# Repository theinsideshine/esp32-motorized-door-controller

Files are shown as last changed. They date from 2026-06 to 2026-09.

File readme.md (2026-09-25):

# ESP32 Motorized Door Controller

<p align="center">
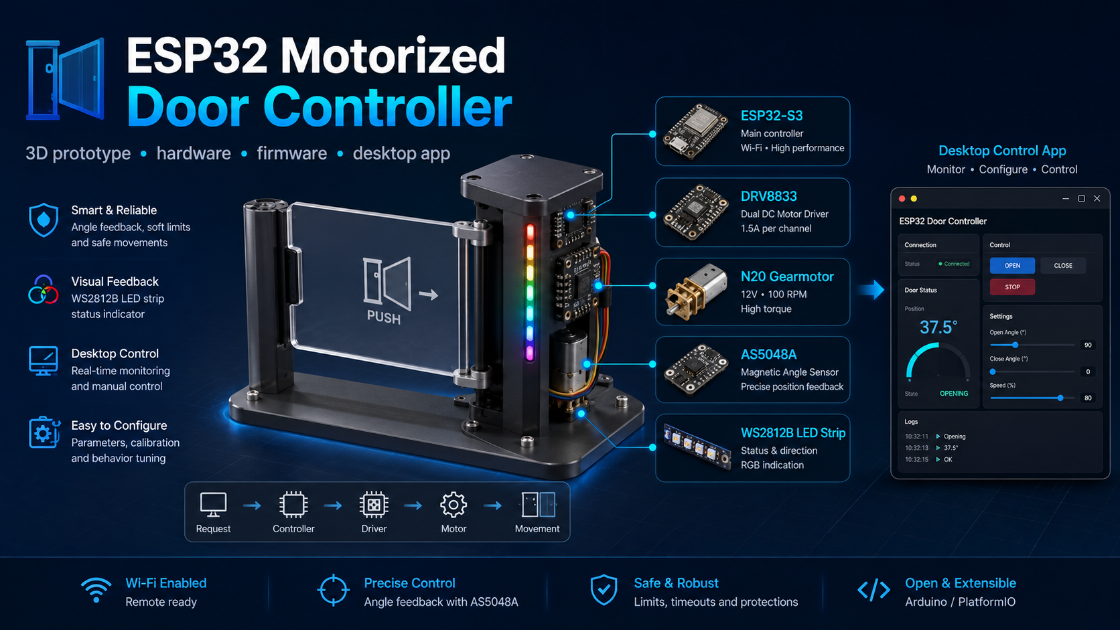
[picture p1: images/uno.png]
ESP32 Motorized Door Controller
  
</p>

> Prototipo funcional a escala de una puerta motorizada de paso, desarrollado como proyecto integrador de I+D para recorrer de forma práctica diseño mecánico, electrónica, firmware embebido, identificación de planta, control y aplicación de escritorio.

---

## 1. Visión del proyecto

Este repositorio documenta la evolución completa de un sistema de control para una **puerta motorizada de paso** basada en ESP32-S3.

El objetivo no fue simplemente lograr que un motor girara hasta una posición. El proyecto se utilizó como un caso de estudio de Ingeniería Electrónica para mostrar cómo una solución real evoluciona mediante:

- diseño CAD e impresión 3D;
- selección e integración de hardware;
- validación experimental;
- firmware monolítico inicial;
- arquitectura modular;
- configuración persistente;
- máquinas de estado;
- instrumentación y Serial Plotter;
- identificación de planta;
- simulación;
- control realimentado;
- diagnóstico de fallas;
- señalización LED;
- aplicación de escritorio.

La idea central es **aprender haciendo**: adquirir conocimientos, aplicarlos sobre un objetivo concreto y convertir las pruebas, errores y decisiones de diseño en competencias profesionales.

---

## 2. Alcance del prototipo

En un desarrollo industrial real se construiría un prototipo funcional representativo del producto final.

A los efectos de este proyecto se implementó un **prototipo funcional a escala**, fabricado principalmente mediante impresión 3D y componentes electrónicos comerciales de bajo costo.

El prototipo permite estudiar el comportamiento del sistema y validar decisiones de arquitectura y control, pero no pretende reproducir todavía:

- dimensiones reales;
- materiales de producción;
- resistencia estructural;
- mecanismos de seguridad certificados;
- embragues o trabas mecánicas de una puerta comercial;
- cargas, inercias y tolerancias de una unidad de tamaño real.

---

## 3. Arquitectura actual

<p align="center">
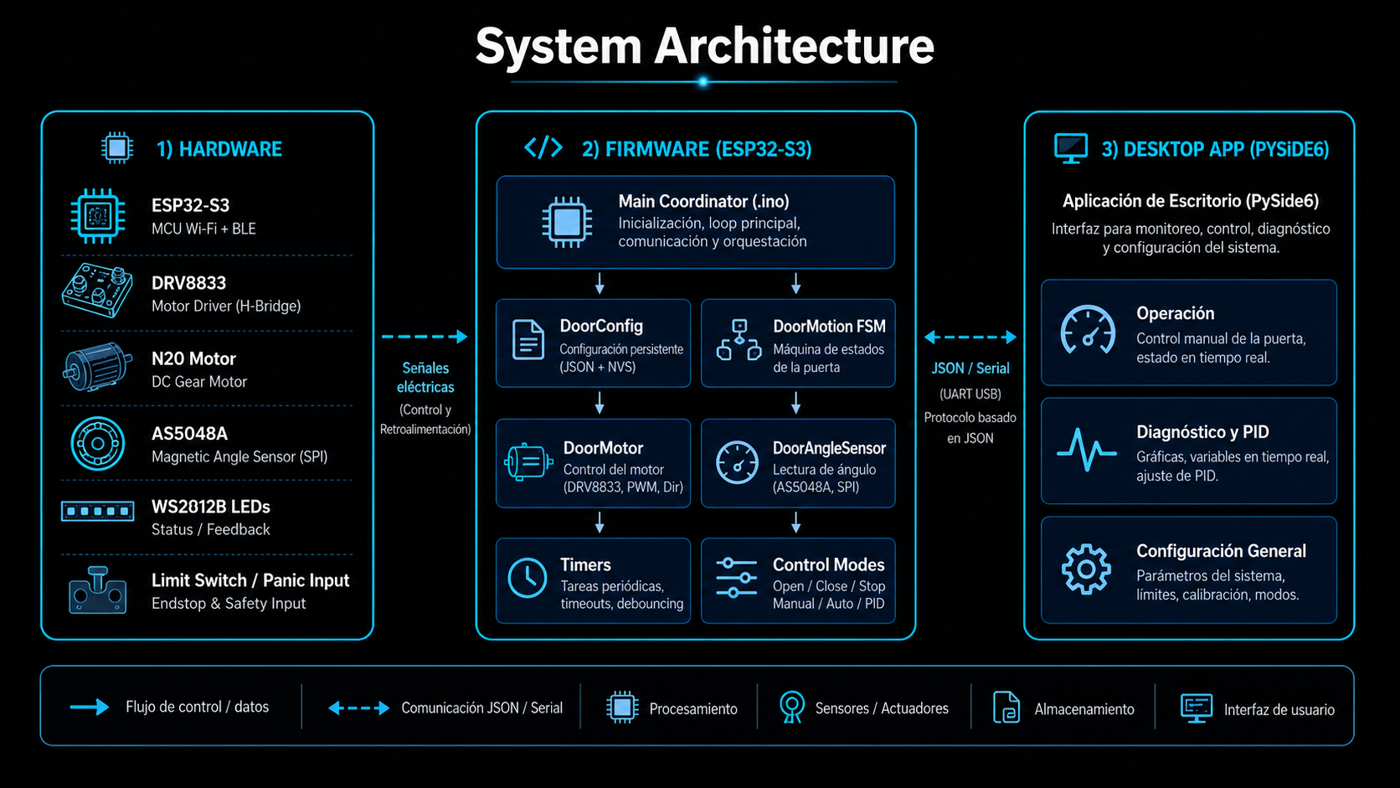
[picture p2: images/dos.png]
Arquitectura general del sistema
  
</p>

La arquitectura separa claramente las responsabilidades principales:

### Hardware

- **ESP32-S3 Dev Module**
- **DRV8833** como puente H
- **Motorreductor N20 de 6 V**
- **AS5048A** como sensor absoluto de posición angular por SPI
- **WS2812B** para señalización visual
- entrada de final de carrera / seguridad
- estructura y mecanismos impresos en 3D

### Firmware

El firmware evolucionó desde un único `.ino` experimental hacia una arquitectura modular.

Responsabilidades principales:

- `motorized_door.ino`  
  Coordinación general del dispositivo.

- `door_config.*`  
  Comunicación JSON, parámetros de configuración, persistencia NVS y requests del host.

- `door_motion.*`  
  Máquina de estados de posicionamiento y estrategias de movimiento.

- `door_motor.*`  
  Abstracción del DRV8833, dirección y PWM.

- `door_angle_sensor.*`  
  Lectura del AS5048A.

- logging / instrumentación  
  Salida humana, JSON de estado y datos para Plotter.

Una decisión importante fue mantener separadas:

1. la lógica del producto;
2. la máquina de posicionamiento;
3. el acceso al hardware;
4. la comunicación;
5. la configuración persistente.

Esto permitió modificar estrategias de control sin reescribir todo el sistema.

### Aplicación de escritorio

La aplicación fue desarrollada en **Python + PySide6**, con asistencia de Codex durante la implementación.

La aplicación no replica la lógica del dispositivo: consume el protocolo y los estados expuestos por el firmware.

Dispone de tres áreas principales:

- **Operación**
- **Diagnóstico y PID**
- **Configuración General**

<p align="center">
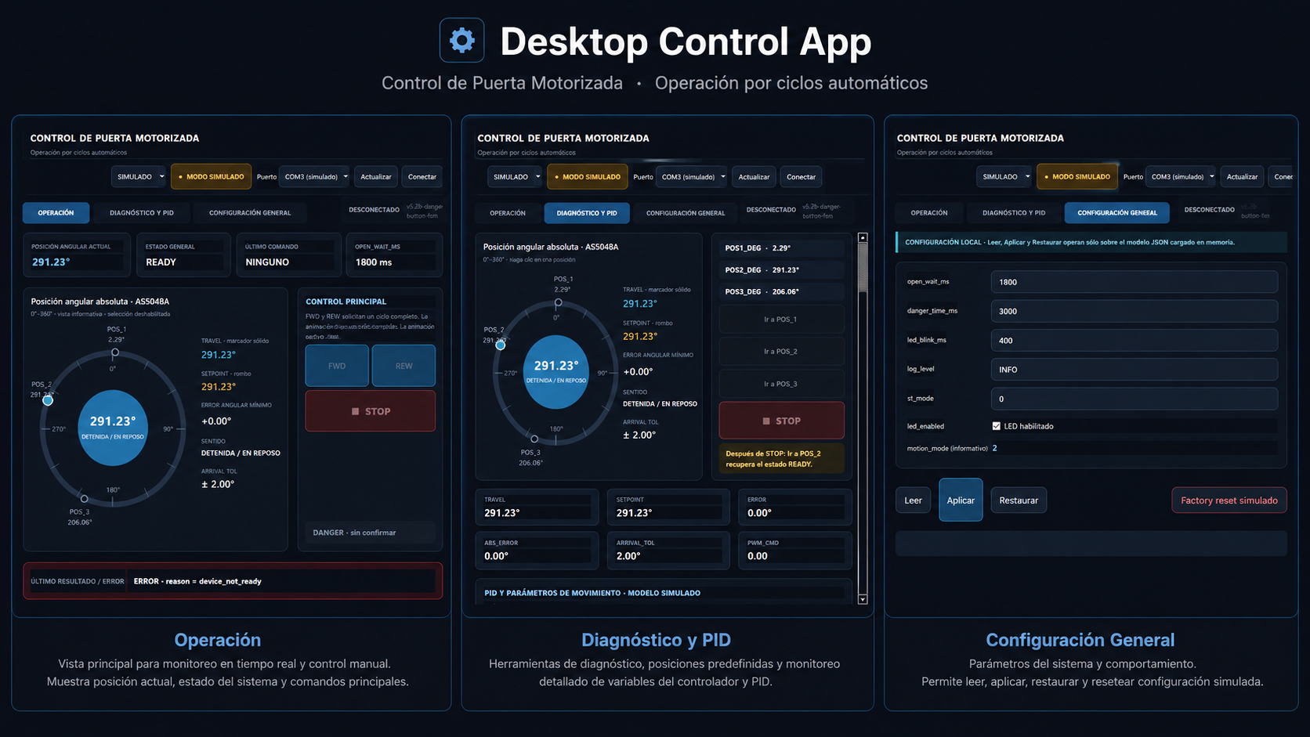
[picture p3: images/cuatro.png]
Pantallas de la aplicación de escritorio
  
</p>

---

## FSM cooperativas: dispositivo, movimiento y LED

<p align="center">
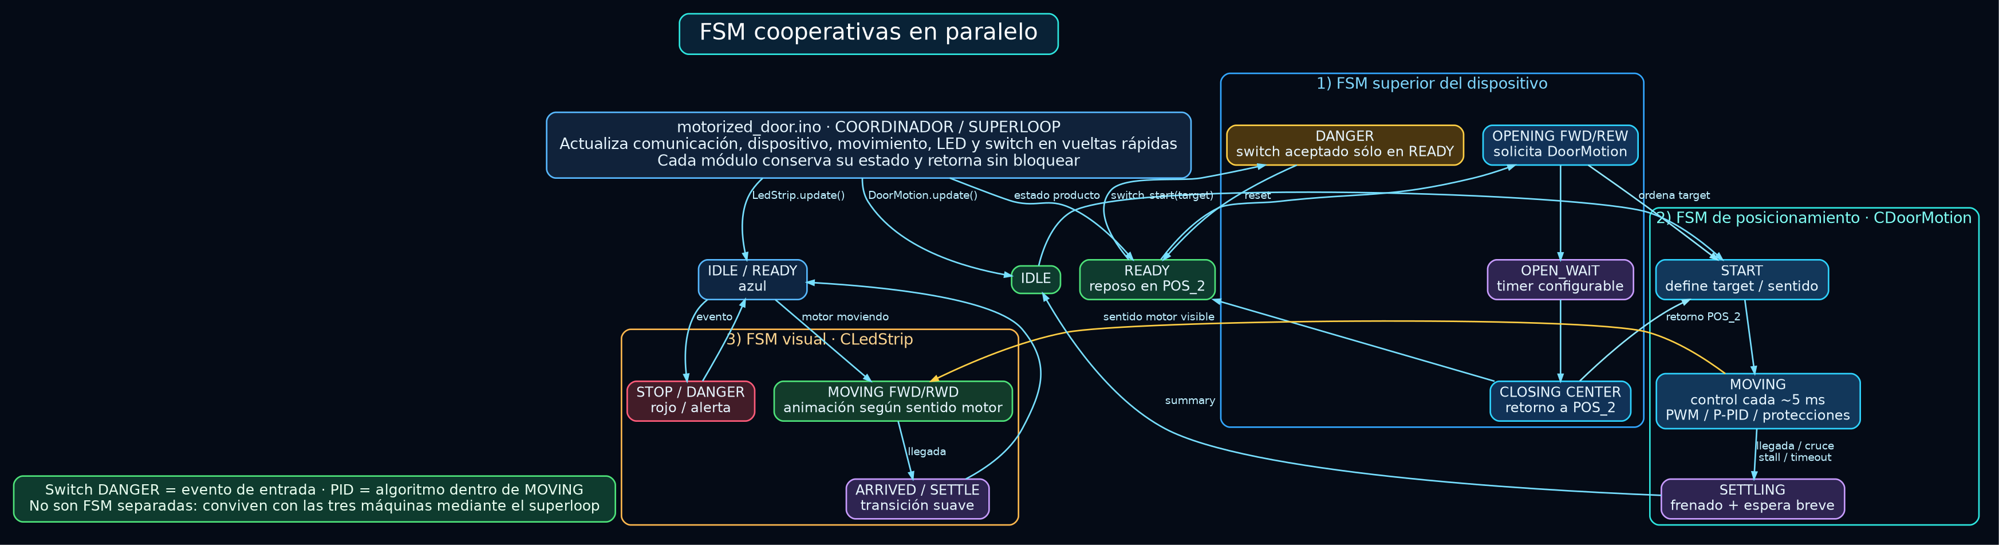
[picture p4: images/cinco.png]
FSM cooperativas en paralelo
  
</p>

En la última evolución del firmware apareció un punto clave de arquitectura: el sistema ya no se entiende como una única máquina de estados, sino como **varias máquinas cooperativas** coordinadas desde el `.ino`.

El `loop()` actúa como coordinador. En cada vuelta atiende comunicación, comandos, switch de seguridad, máquina superior del dispositivo, movimiento y animación LED. La regla central es que cada módulo debe **conservar su propio estado y volver rápido**, sin quedarse bloqueando al resto del sistema.

Conviven tres FSM principales:

### 1. FSM superior del dispositivo

Representa el comportamiento del producto completo:

```text
BOOT
CENTERING
READY
OPENING_FWD / OPENING_REW
OPEN_WAIT
CLOSING_CENTER
STOPPED
DANGER
```

Esta FSM decide qué acciones tienen sentido según el estado general. Por ejemplo, el switch o botón de `DANGER` no debe tener el mismo significado durante `READY` que durante una apertura o un retorno al centro.

En esta capa viven las reglas del producto:

- iniciar centrado al arranque;
- quedar operativo en `POS_2`;
- aceptar ciclos `FWD` y `REW`;
- esperar `open_wait_ms`;
- volver al centro;
- atender `STOP`;
- aceptar o ignorar el evento `DANGER` según corresponda.

### 2. FSM de posicionamiento `CDoorMotion`

Esta FSM resuelve el movimiento físico hacia un objetivo:

```text
IDLE
START
MOVING
SETTLING
HOLDING reservado
```

Durante `MOVING` puede usar distintas estrategias de control:

```text
motion_mode = 0  PWM fijo
motion_mode = 1  approach no-PID
motion_mode = 2  control realimentado P/PID según parámetros
```

También concentra criterios de llegada y protección:

- tolerancia;
- cruce del objetivo;
- timeout;
- stall;
- cancelación;
- settle final.

El PID no es una FSM aparte. Es un algoritmo de control que se ejecuta dentro de `MOVING` cuando el modo configurado lo requiere.

### 3. FSM visual `CLedStrip`

La tira WS2812B mantiene su propia lógica temporal:

```text
IDLE / READY
MOVING_FWD
MOVING_RWD
ARRIVED / SETTLE
STOP / DANGER
```

Esta máquina no debe mover el motor ni decidir el estado del producto. Su responsabilidad es representar visualmente el estado que ya fue decidido por las otras capas.

El caso del tironeo del motor mostró por qué esta separación es importante: el LED no provocaba el problema mecánico; estaba mostrando en tiempo real una inversión breve del sentido del motor. Lo que parecía un síntoma visual aislado terminó siendo evidencia de la causa.

<p align="center">
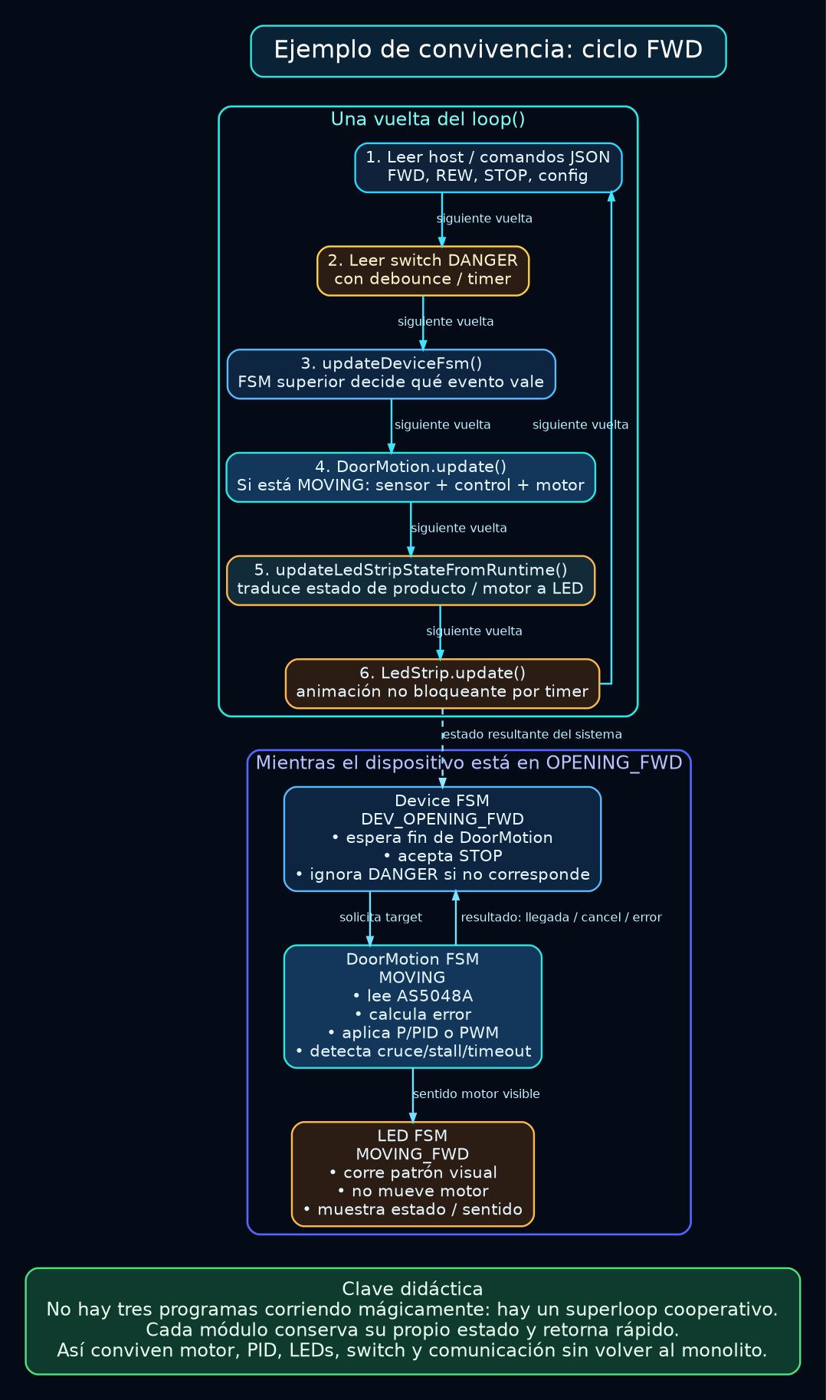
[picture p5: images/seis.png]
Ejemplo de convivencia de FSM durante un ciclo FWD
  
</p>

Durante un ciclo `FWD`, por ejemplo, ocurren varias cosas al mismo tiempo desde el punto de vista del usuario, pero no como hilos separados ni como tareas bloqueantes:

```text
Device FSM     : DEV_OPENING_FWD
DoorMotion FSM : MOVING
LED FSM        : MOVING_FWD
Switch DANGER  : leído, pero la FSM superior decide si lo acepta
Comunicación   : sigue disponible para STOP / estado / diagnóstico
```

La conclusión didáctica es importante:

> No hay tres programas corriendo mágicamente. Hay un **superloop cooperativo** donde cada módulo conserva su estado, ejecuta una pequeña parte de su trabajo y devuelve el control.

Esta arquitectura permitió que convivan motor, sensor, PID, LED, switch de seguridad y aplicación desktop sin volver al firmware monolítico inicial.

## 4. Evolución del proyecto

<p align="center">
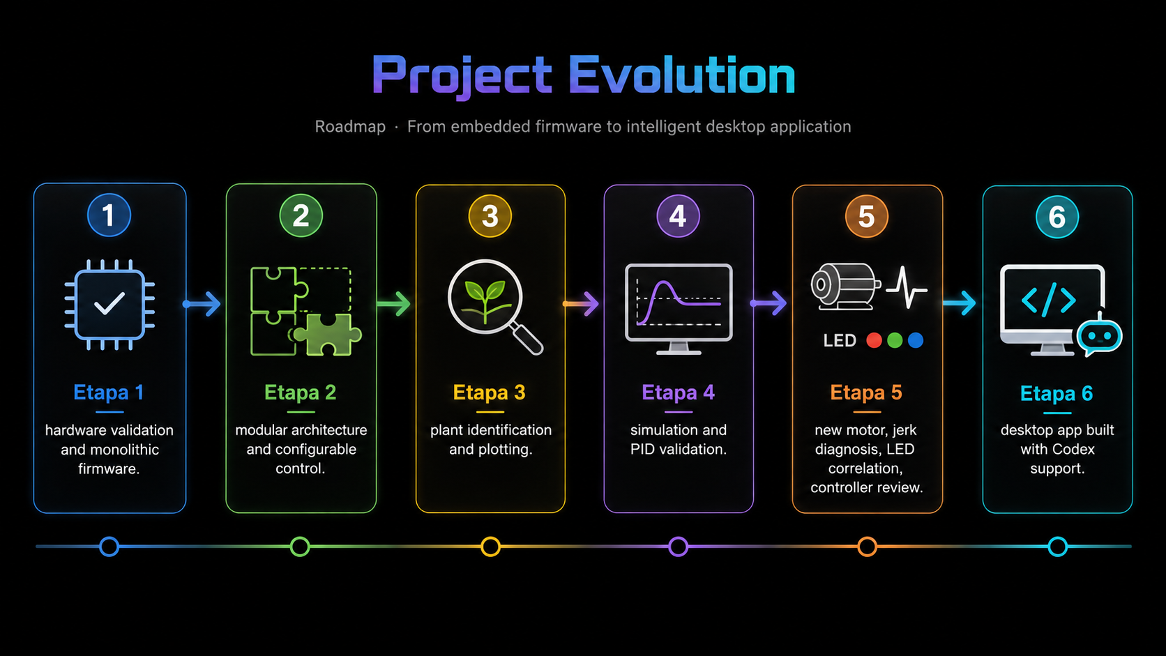
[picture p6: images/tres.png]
Evolución técnica del proyecto
  
</p>

El proyecto se desarrolló de forma incremental, conservando versiones funcionales como **baseline** antes de introducir cambios de arquitectura o control.

### Etapa 1 — Validación electromecánica y firmware monolítico

Primero se validó lo esencial:

- diseño CAD;
- impresión 3D;
- montaje del N20;
- alineación mecánica;
- prueba directa a 6 V en ambos sentidos;
- transmisión del movimiento hacia la puerta;
- DRV8833;
- AS5048A;
- primer firmware monolítico;
- movimiento manual y automático;
- comportamiento con PWM fijo.

La instrumentación mostró que el ESP32, el SPI y el ciclo de control respondían con margen suficiente.

El problema dominante no estaba en la velocidad de procesamiento: estaba en la **dinámica del mecanismo**.

Se observaron:

- inercia después del corte;
- sobrepaso;
- fricción;
- diferencias según sentido;
- zonas de arranque marginal;
- stalls bajo determinadas cargas.

### Etapa 2 — Arquitectura modular y control configurable

Una vez validada la plataforma física se evitó seguir creciendo sobre el firmware experimental.

Se separaron responsabilidades y se incorporaron:

- configuración JSON;
- persistencia NVS;
- FSM de posicionamiento independiente;
- abstracción del motor;
- abstracción del sensor;
- modos de movimiento configurables.

Se conservaron distintos `motion_mode` para poder comparar estrategias sobre la misma arquitectura.

El modo de PWM fijo quedó como baseline y se agregó un perfil **approach no-PID**, con:

- boost de arranque;
- PWM de movimiento;
- PWM lento;
- zona de aproximación;
- tiempo de boost.

El approach mejoró algunos recorridos y redujo stalls, pero mostró otro problema: cada mejora empírica agregaba nuevos parámetros dependientes de la mecánica.

### Etapa 3 — Identificación de planta

Para dejar de ajustar solamente por prueba y error se instrumentó el sistema con Serial Plotter.

La identificación se realizó con:

```text
motion_mode = 0
PWM fijo = 70, 75 y 80
```

Se registró principalmente:

```text
travel vs tiempo
```

Esto evitó confusiones producidas por el wrap angular `0° / 360°`.

En la zona útil del recorrido el comportamiento resultó aproximadamente lineal.

Modelo inicial:

```text
velocidad_deg_s ≈ 4.97 * (PWM - 18.0)
```

El modelo no pretende reproducir todos los efectos físicos. Su objetivo fue capturar la dinámica dominante y proporcionar una base para simulación.

Un hallazgo relevante fue que PWM 70 podía alcanzar una velocidad normal una vez iniciado el movimiento, pero presentar un retardo de arranque importante en determinada condición. Esto separó claramente:

- dinámica en régimen;
- fricción estática / zona muerta de arranque.

### Etapa 4 — Simulación y control realimentado

Antes de modificar nuevamente el firmware se simuló la planta en Python.

La estrategia fue:

```text
planta medida
    ↓
modelo
    ↓
simulación
    ↓
constantes iniciales
    ↓
hardware real
    ↓
recalibración
```

La simulación entregó una base conservadora cercana al comportamiento real.

Una primera implementación utilizó valores próximos a:

```text
Kp = 0.70
Ki = 0
Kd = 0.05
PWM max = 80
```

En el banco real fue necesario corregir principalmente las zonas que el modelo simple no representaba:

- fricción;
- PWM mínimo efectivo;
- arranque;
- carga;
- comportamiento muy próximo al target.

Durante esa etapa también se evaluó una integral pequeña y limitada para corregir error fino.

El aprendizaje importante fue que **la simulación no reemplaza al hardware**. Sirve para reducir el espacio de búsqueda y comenzar los ensayos físicos con valores razonables.

> **El controlador se sintonizó con relativa facilidad porque antes se había realizado el trabajo de identificación de planta, simulación y conservación de un baseline.**

En un producto real existirían motor, eje, embrague, puerta, rodamientos, tolerancias de fabricación y múltiples piezas. Cada unidad modifica ligeramente la planta. Una práctica razonable sería caracterizar una población de equipos, obtener una planta representativa y luego realizar una calibración homogénea con márgenes adecuados.

### Etapa 5 — Motor nuevo, tironeo, LED y revisión del controlador

Durante la integración de la tira WS2812B fue necesario reemplazar el motor N20.

En ese momento aparecieron simultáneamente dos síntomas:

- un tironeo mecánico;
- un salto visual en la animación LED.

El firmware todavía estaba en evolución, por lo que fue necesario evitar conclusiones rápidas.

Se utilizaron las capacidades construidas en etapas anteriores:

- modos de ejecución;
- simulación del movimiento LED;
- PWM fijo;
- Plotter;
- parámetros configurables;
- separación entre motor, LED y máquina de movimiento.

Esto permitió aislar progresivamente el problema.

El análisis mostró que el término derivativo estaba produciendo breves inversiones de la salida de control. El puente H obedecía esas inversiones y el motor cambiaba momentáneamente de sentido.

La animación LED consultaba el mismo estado de dirección del motor.

Por lo tanto:

> El LED no provocaba el tironeo.  
> El tironeo y el salto visual eran dos manifestaciones de la misma inversión breve de sentido.

La observación que inicialmente parecía un segundo error terminó convirtiéndose en evidencia independiente de la causa.

La configuración operativa se simplificó posteriormente a:

```text
pid_kp = 0.70
pid_ki = 0
pid_kd = 0
```

Aunque históricamente el proyecto recorrió PD y PID, en esta planta y en este prototipo no fue necesario conservar los términos I y D para obtener el comportamiento deseado.

Esta etapa confirmó otra conclusión importante:

> **Una arquitectura escalable, configurable y con modos de prueba no es solamente una cuestión de prolijidad de software: es una herramienta de diagnóstico de I+D.**

### Etapa 6 — Aplicación de escritorio

Con el firmware y el protocolo ya consolidados se desarrolló la aplicación de escritorio.

Tecnología:

```text
Python
PySide6
JSON / Serial
```

La implementación se realizó de manera incremental con asistencia de Codex, pero manteniendo una separación clara de responsabilidades:

- el firmware conserva la autoridad sobre el dispositivo;
- la app muestra y solicita;
- los estados reales se obtienen del protocolo;
- las decisiones de arquitectura y los criterios de validación pertenecen al proceso de ingeniería.

La interfaz incluye:

#### Operación

- posición angular actual;
- estado general;
- último comando;
- tiempo de espera de apertura;
- representación angular del AS5048A;
- comandos `FWD`, `REW` y `STOP`;
- visualización de estado y errores.

#### Diagnóstico y PID

- POS_1 / POS_2 / POS_3;
- `travel`;
- `setpoint`;
- error angular;
- error absoluto;
- tolerancia;
- `pwm_cmd`;
- parámetros de movimiento/control;
- comandos de posicionamiento para diagnóstico.

#### Configuración General

- `open_wait_ms`;
- `danger_time_ms`;
- `led_blink_ms`;
- `log_level`;
- `st_mode`;
- `led_enabled`;
- información de `motion_mode`;
- lectura, aplicación y restauración de configuración.

La aplicación incluye además un **modo simulado**, útil para desarrollar y validar la interfaz sin depender permanentemente del hardware conectado.

---

## 5. Estado funcional actual

El prototipo evolucionó desde un posicionador experimental hacia una máquina de dispositivo.

La operación normal tiene como posición de reposo:

```text
POS_2
```

La lógica superior permite solicitar ciclos hacia ambos lados mediante:

```text
FWD
REW
STOP
```

Conceptualmente, un ciclo de apertura realiza:

```text
READY
  ↓
apertura hacia un extremo
  ↓
espera configurable
  ↓
retorno a POS_2
  ↓
READY
```

Al iniciar el dispositivo se busca llevar la puerta a la posición central de referencia antes de habilitar la operación normal.

La señalización LED se integra con los estados de movimiento y seguridad sin bloquear la ejecución principal.

---

## 6. Hardware de referencia

| Componente | Uso |
|---|---|
| ESP32-S3 Dev Module | Controlador principal |
| DRV8833 | Puente H / accionamiento del motor |
| N20 6 V con reductora | Actuador del prototipo |
| AS5048A | Sensor absoluto de posición angular |
| WS2812B | Indicadores visuales |
| Final de carrera / entrada de seguridad | Referencia y protección |
| Piezas impresas en 3D | Estructura y transmisión mecánica |

### Pines usados

```text
DRV8833 STBY : GPIO4
DRV8833 AIN2 : GPIO16
DRV8833 AIN1 : GPIO17

AS5048A CS   : GPIO10
AS5048A MOSI : GPIO11
AS5048A SCK  : GPIO12
AS5048A MISO : GPIO13

FC_L         : GPIO14
WS2812B      : GPIO6
```

---

## 7. Posiciones calibradas del prototipo

```text
POS_1 =   2.29°
POS_2 = 291.23°
POS_3 = 206.06°
```

El sistema trabaja con un sensor absoluto `0°–360°`, por lo que el firmware debe contemplar correctamente el **wrap angular**.

Ejemplo:

```text
posición = 358°
target   =   2°
```

La distancia angular correcta no es `-356°`, sino `+4°` por el recorrido corto.

---

## 8. Conceptos de control implementados o estudiados

Durante el desarrollo se trabajó con:

- PWM fijo;
- zona muerta;
- PWM mínimo efectivo;
- boost de arranque;
- zona lenta;
- error angular;
- tolerancia de llegada;
- cruce del target;
- stall;
- timeout;
- settle;
- control P;
- control PD;
- control PID;
- saturación;
- integral limitada;
- identificación de planta;
- simulación;
- realimentación absoluta.

El objetivo no fue demostrar que un PID siempre sea necesario.

El proyecto muestra justamente lo contrario: **el controlador debe responder a la planta real y al objetivo de producto**.

La evolución PD/PID fue técnicamente útil porque permitió estudiar la dinámica y encontrar una solución robusta. La evidencia posterior llevó a simplificar el controlador operativo.

---

## 9. Limitaciones mecánicas del prototipo

El N20 utilizado es apropiado para un prototipo pequeño, pero debe respetarse su naturaleza mecánica.

Estos motorreductores se utilizan normalmente para transmitir torque mediante:

- ruedas;
- engranajes;
- poleas;
- acoples alineados.

No están pensados para recibir esfuerzos axiales o laterales importantes directamente sobre su eje.

Durante el proyecto se observó que las cargas externas y los montajes experimentales pueden introducir:

- palanca sobre el eje;
- esfuerzos laterales;
- rozamiento variable;
- juego en la reductora;
- condiciones que no representan el producto final.

Por este motivo las pruebas actuales evitan aplicar cargas laterales arbitrarias sobre el eje.

En un equipo comercial deberían utilizarse mecanismos adecuados de:

- eje;
- soporte;
- rodamientos;
- acople;
- embrague;
- traba o mecanismo de liberación.

---

## 10. Seguridad y HOLDING

El proyecto diferencia **posicionamiento** de **seguridad mecánica**.

Un controlador puede mantener o corregir una posición, pero una puerta real destinada al paso de personas no debería depender únicamente del torque del motor o de un PID para bloquear un acceso.

Un producto real debería evaluar elementos como:

- embrague;
- traba;
- solenoide;
- liberación ante fuerza externa;
- detección de obstrucción;
- límites de torque;
- condiciones de emergencia.

Por esta razón el concepto de `HOLDING` activo se mantuvo reservado durante la etapa de posicionamiento del prototipo.

---

## 11. Protocolo y configuración

El firmware expone información y configuración mediante JSON.

Ejemplos de operaciones utilizadas durante el desarrollo:

```json
{"info":"version"}
```

```json
{"info":"all-params"}
```

```json
{"cmd":"go","pos":1}
```

```json
{"cmd":"fwd"}
```

```json
{"cmd":"rew"}
```

```json
{"cmd":"stop"}
```

La configuración persistente permite recalibrar parámetros sin modificar ni recompilar la arquitectura.

---

## 12. Estructura del repositorio

La estructura puede variar entre branches históricos, pero conceptualmente el repositorio contiene:

```text
esp32-motorized-door-controller/
├── firmware/
│   ├── ...
│   └── beam_app/
├── doc/
│   ├── conceptos de control/
│   ├── etapa1/
│   ├── etapa2/
│   ├── etapa3/
│   ├── etapa4/
│   ├── etapa5/
│   ├── etapa6/
│   ├── fsm/
│   ├── conclusiones.pptx
│   └── puerta_motorizada_estrategia_desarrollo_v01.pdf
├── images/
│   ├── uno.png
│   ├── dos.png
│   ├── tres.png
│   ├── cuatro.png
│   ├── cinco.png
│   └── seis.png
└── README.md
```

## 13. Documentación del proyecto y serie de videos

La documentación fue separada en capítulos para conservar el razonamiento, las pruebas y la evidencia de cada decisión.

La idea es acompañar cada bloque documental con uno o más videos. Los capítulos todavía no publicados mantienen enlaces temporales que serán reemplazados a medida que avance la serie.

> La serie completa recorre el proyecto desde la presentación inicial hasta las conclusiones. No busca condensar todo en un único video: cada etapa conserva su propio contexto, ensayos, errores y decisiones.

**Playlist completa:**  
[ESP32 Motorized Door Controller — Serie de videos](https://www.youtube.com/playlist?list=PLGqY9vY1gnuE)

| Capítulo | Documentación | Video |
|---|---|---|
| Presentación general | [Estrategia de desarrollo](doc/puerta_motorizada_estrategia_desarrollo_v01.pdf) | [Video — Presentación](https://youtu.be/tGlV2I14xzM?si=gqTcPS8floOHWkKc) |
| Conceptos de control 1 | [Material de conceptos](doc/conceptos%20de%20control/) | [Video — Conceptos de Control 1](https://youtu.be/-zWi4smrSy0?si=rCGWmWPPGxEtW44c) |
| Conceptos de control 2 | [Material de conceptos](doc/conceptos%20de%20control/) | [Video — Conceptos de Control 2](https://youtu.be/oZFYpoFS2YE?si=7HI8qRgSr294EGh5) |
| Etapa 1 | [Documentación Etapa 1](doc/etapa1/) | [Video — Etapa 1](https://youtu.be/AiCed6doYCs?si=erTG39RUByldZ4Nc) |
| Etapa 2 | [Documentación Etapa 2](doc/etapa2/) | [Video — Etapa 2](https://youtu.be/_OtV3IECt6k?si=y8wfF_4OTmgoHx5V) |
| Etapas 3 y 4 | [Documentación Etapa 3](doc/etapa3/) · [Documentación Etapa 4](doc/etapa4/) | [Video — Etapas 3 y 4](https://youtu.be/SIyOGEayfiI?si=ntqV_h6SsCf4ipXb) |
| Etapa 5 | [Documentación Etapa 5](doc/etapa5/) | [Video — Etapa 5](https://youtu.be/PENDIENTE_ETAPA_5) |
| Etapa 6 | [Documentación Etapa 6](doc/etapa6/) | [Video — Etapa 6](https://youtu.be/PENDIENTE_ETAPA_6) |
| FSM cooperativas | [Documentación FSM](doc/fsm/) | [Video — FSM](https://youtu.be/PENDIENTE_FSM) |
| Conclusiones | [Presentación de conclusiones](doc/conclusiones.pptx) | [Video — Conclusiones](https://youtu.be/PENDIENTE_CONCLUSIONES)<br>[Demo final del proyecto](https://youtu.be/0kEP7_TdRBw) |
### Presentación general

**Marco, objetivo y estrategia de desarrollo**

Introduce el problema, el alcance del prototipo y la forma en que se planteó el trabajo como proyecto integrador de Ingeniería Electrónica e I+D.

El documento de referencia es:

```text
doc/puerta_motorizada_estrategia_desarrollo_v01.pdf

### Conceptos de control

Material introductorio para:

- posición y error;
- tolerancia;
- cruce;
- stall;
- timeout;
- wrap `0° / 360°`;
- planta;
- simulación;
- P / I / D;
- saturación y anti-windup.

### Etapa 1

**Validación inicial de hardware y plataforma electromecánica**

Desde CAD y montaje hasta el primer firmware monolítico y las pruebas con PWM fijo.

### Etapa 2

**Arquitectura modular y control configurable**

Separación de responsabilidades, JSON, NVS, FSM y perfil approach no-PID.

### Etapa 3

**Identificación de planta**

Serial Plotter, curvas `travel/tiempo`, velocidad y modelo inicial.

### Etapa 4

**Simulación y validación del controlador**

Del modelo Python al hardware y pruebas de carga.

### Etapa 5

**Caso de estudio: motor nuevo, tironeo y LED**

Investigación de una anomalía, aislamiento de variables y revisión de la acción derivativa.

### Etapa 6

**Aplicación desktop**

Interfaz de operación, diagnóstico, configuración y modo simulado.

### FSM cooperativas

**Dispositivo, posicionamiento y señalización visual**

Este capítulo concentra la evolución final de la arquitectura hacia varias máquinas de estado cooperativas:

- FSM superior del dispositivo;
- FSM de posicionamiento `CDoorMotion`;
- FSM visual `CLedStrip`;
- coordinación mediante superloop;
- convivencia con comunicación, sensor, PID y eventos de seguridad.

La documentación específica se encuentra en:

```text
doc/fsm/
```

### Conclusiones

**Cierre del prototipo y próximas etapas**

El cierre resume lo aprendido durante todo el recorrido y deja explícito que el prototipo actual no representa el final de un desarrollo profesional.

Entre las etapas futuras quedan:

- decidir el tratamiento definitivo de la acción derivativa;
- corregir comportamientos pendientes de desconexión de la app;
- construir un prototipo a escala real;
- verificar nuevamente la planta y el controlador sobre esa mecánica;
- evaluar el BOM del prototipo real;
- estudiar embrague y mecanismos de liberación;
- estudiar solenoides o trabas para bloqueo mecánico cuando el producto lo requiera;
- diseñar y validar el nuevo hardware de control;
- avanzar desde un prototipo funcional hacia criterios reales de fabricación y producción.

La presentación de cierre se encuentra en:

```text
doc/conclusiones.pptx
```

---

## 14. Decisiones de ingeniería destacadas

El proyecto fue construido alrededor de algunas reglas simples:

### Validar antes de abstraer

El primer firmware fue deliberadamente directo. Su función era demostrar que el hardware y la mecánica podían funcionar.

La modularización se realizó cuando las responsabilidades ya eran suficientemente conocidas.

### Conservar baselines

Cada cambio importante parte de una versión funcional conocida.

Esto permite diferenciar:

```text
problema nuevo
```

de:

```text
problema que ya existía
```

### Instrumentar antes de suponer

Cuando apareció sobrepaso, se midieron tiempos.

Cuando apareció comportamiento extraño, se usó Plotter.

Cuando apareció el tironeo, se aislaron LED, motor, PWM y controlador.

### Una observación no es todavía una causa

El salto visual del LED parecía estar relacionado con el tironeo.

Finalmente se comprobó que ambos eran efectos de una tercera causa común: el cambio momentáneo de sentido ordenado al motor.

### La experiencia guía qué medir

Los datos no seleccionan por sí solos el siguiente ensayo.

El proceso real fue:

```text
observar
   ↓
interpretar
   ↓
formular hipótesis
   ↓
medir
   ↓
decidir
```

---

## 15. Valor didáctico

El proyecto integra competencias de distintas áreas de Ingeniería Electrónica:

- sistemas de representación y CAD;
- fabricación 3D;
- electrónica;
- electrónica de potencia;
- microcontroladores;
- programación;
- programación avanzada;
- arquitectura de software;
- automatización;
- sistemas de control;
- instrumentación;
- análisis experimental;
- proyecto final e I+D.

Más que presentar una solución única, el repositorio documenta **un camino posible**.

La intención es que el estudiante pueda observar cómo los conocimientos adquiridos durante la carrera se combinan cuando aparece un problema real y cómo la experiencia técnica permite elegir qué hipótesis probar, qué variable medir y cuándo una decisión debe revisarse.

---

## 16. Estado actual resumido

```text
Diseño CAD / impresión 3D        : validado para prototipo
Hardware base                    : validado
ESP32-S3 + DRV8833               : operativo
AS5048A                           : operativo
WS2812B                           : integrado
Firmware modular                 : operativo
Configuración JSON               : operativa
Persistencia NVS                 : operativa
FSM de posicionamiento           : operativa
FSM de dispositivo               : integrada
Identificación de planta         : realizada
Simulación                       : realizada
Control realimentado             : validado
Configuración operativa actual   : Kp=0.70, Ki=0, Kd=0
App PySide6                      : integrada / en validación
Modo simulado de app             : disponible
Documentación por etapas         : disponible
```

---

## 17. Próximas validaciones

Entre las pruebas útiles pendientes queda una especialmente interesante para cerrar el vínculo entre modelo y planta:

1. utilizar un PWM no empleado en la identificación original;
2. predecir velocidad con el modelo;
3. medir la velocidad real;
4. comparar predicción y ensayo.

Por ejemplo:

```text
PWM = 77
```

permitiría comprobar si el modelo identificado a partir de PWM 70, 75 y 80 conserva capacidad predictiva sobre un punto intermedio no utilizado para obtener la recta.

También queda abierta la validación del comportamiento completo de la aplicación contra el hardware real y la evolución de los elementos mecánicos hacia una plataforma más representativa del producto comercial.

---

## 18. Idea final

Este proyecto comenzó con una pregunta simple:

> **¿Podemos mover una puerta?**

La evolución llevó a preguntas mucho más interesantes:

> ¿Podemos medirla?  
> ¿Podemos explicar por qué se mueve así?  
> ¿Podemos controlar su comportamiento?  
> ¿Podemos diagnosticar una anomalía sin romper lo que ya funciona?  
> ¿Podemos construir una arquitectura que permita seguir evolucionando?

Ese recorrido es, en definitiva, el objetivo principal del proyecto.

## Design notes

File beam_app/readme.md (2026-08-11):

# Door Controller App

Aplicación desktop en Python/PySide6 para operar y diagnosticar el controlador de una puerta motorizada mediante un ESP32.

## Funciones de la demo

- Conexión serie real o simulación local.
- Lectura de versión, configuración y posición angular absoluta.
- Ciclos `FWD`, `REW` y parada `STOP`.
- Movimientos directos a `POS_1`, `POS_2` y `POS_3`.
- Edición y confirmación de `pos1_deg`, `pos2_deg`, `pos3_deg` y `pwm_move`.
- Visualización de los eventos estructurados `ack`, `motion-complete` y `cycle-complete`.

## Arquitectura

```text
door_controller_app/
├── main.py
├── controllers/
│   └── main_controller.py
├── core/
│   ├── serial_manager.py
│   └── serial_event_queue.py
├── ui/
│   ├── main_window.py
│   └── door_position_widget.py
├── config/
│   └── simulation_data.json
├── requirements.txt
├── run.bat
├── run_first.bat
└── run.sh
```

La lectura serie se mantiene desacoplada de Qt: `SerialManager` produce líneas en `SerialEventQueue` y `MainController` consume la cola desde un `QTimer` en el hilo de la interfaz.

## Instalación

Windows:

```bat
cd door_controller_app
run_first.bat
```

Linux:

```bash
cd door_controller_app
python3 -m venv .venv
source .venv/bin/activate
pip install -r requirements.txt
```

## Ejecución

Windows:

```bat
run.bat
```

Linux:

```bash
./run.sh
```

Ejecución manual desde la raíz:

```bash
python main.py
```

## Protocolo usado en la demo

La aplicación solicita los valores confirmados con:

```json
{"info":"all-params"}
```

Las posiciones, PWM y movimientos se envían con los mensajes definidos por el firmware:

```json
{"pos1_deg":2.29}
{"pos2_deg":291.23}
{"pos3_deg":206.06}
{"pwm_move":80}
{"cmd":"go","pos":1}
{"cmd":"go","pos":2}
{"cmd":"go","pos":3}
{"cmd":"fwd"}
{"cmd":"rew"}
{"cmd":"stop"}
```

En modo real, los campos no se consideran confirmados hasta recibir nuevamente `all-params`. Los logs humanos del firmware se muestran en consola, pero no se usan para reconstruir estados.

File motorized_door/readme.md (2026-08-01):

# `esp32-motorized-door-controller`

Firmware y aplicación de escritorio para un prototipo de puerta motorizada basado en ESP32-S3, DRV8833, motor N20, sensor absoluto AS5048A y tira WS2812B.

El repositorio está organizado como monorepo:

```text
firmware / motorized_door
  Control embebido, JSON/NVS, posicionamiento, motor, sensor y FSM LED.

beam_app
  Prototipo de aplicación de escritorio desarrollado con PySide6/Qt.
```

---

## Estado actual

Branch de trabajo:

```text
wip/v5.1a-led-strip-fsm
```

Baseline estable de partida:

```text
commit 7883b25  Set validated defaults for new motor
tag    v5.1e-validated-defaults
```

Versión de esta evolución:

```text
v5.2c-runtime-events
```

La versión conserva la FSM superior de demo y el estado `DANGER`, y agrega
eventos JSON de finalización para que la aplicación desktop pueda distinguir
un `ack` de inicio de la finalización real del movimiento o ciclo. También
expone `device_state` y `current_deg` en `all-params`.

---

## Resultado validado

El prototipo funciona actualmente con:

```text
centrado automático al arrancar en modo normal
ciclo fwd: POS_2 -> POS_1 -> espera -> POS_2
ciclo rew: POS_2 -> POS_3 -> espera -> POS_2
movimiento directo hacia POS_1, POS_2 y POS_3
sensor AS5048A por SPI
control de posición durante MOVING
sin HOLDING activo
FSM LED no bloqueante
transición suave de llegada
simulación runtime de posición para diagnóstico LED
configuración persistente JSON/NVS
Serial Plotter para análisis de planta y control
```

Set operativo validado con el motor nuevo:

```text
motion_mode=2
pid_kp=0.7
pid_ki=0
pid_kd=0
pid_pwm_max=80
pid_pwm_min_effective=70
pid_min_effective_error_deg=2
auto_tolerance_deg=2
control_period_us=5000
```

Con ese set:

```text
sin tironeo del motor
animación LED fluida
reason=posicion_alcanzada
stall_count=0/3
```

---

## Hardware

```text
ESP32-S3 Dev Module
DRV8833
Motor N20 con reductora, VM=6 V
Sensor absoluto AS5048A por SPI
Tira WS2812B
Pulsador DANGER
Prototipo mecánico impreso en 3D
```

### Pines

```text
DRV8833:
  STBY = GPIO4
  AIN2 = GPIO16
  AIN1 = GPIO17

AS5048A SPI:
  CS   = GPIO10
  MOSI = GPIO11
  SCK  = GPIO12
  MISO = GPIO13

Pulsador DANGER:
  GPIO14 con INPUT_PULLUP
  NORMAL = LOW
  ACTIVO = HIGH
  Se atiende solamente en DEV_READY, con la puerta centrada en POS_2.

WS2812B:
  DATA = GPIO6
```

### Posiciones calibradas

```text
POS_1 = 2.29°
POS_2 = 291.23°
POS_3 = 206.06°
```

Sentidos lógicos:

```text
RIGHT / REWIND  -> baja ángulo
LEFT  / FORWARD -> sube ángulo
```

---

## Arquitectura del firmware

```text
motorized_door.ino
  Coordinador del producto y FSM superior.
  BOOT, CENTERING, READY, OPENING, OPEN_WAIT, CLOSING, DANGER y STOPPED.
  Crea los CTimer de espera y DANGER y consulta la copia RAM de CDoorConfig.
  Procesa pedidos runtime e inyecta callbacks físicos.

CDoorConfig
  Protocolo JSON por Serial.
  Copia RAM de configuración.
  Persistencia NVS.
  Requests pendientes para el main.

CDoorMotion
  Máquina de estados de posicionamiento.
  START -> MOVING -> SETTLING -> IDLE.
  Llegada, cruce, timeout, stall, cancelación y summary.
  Publica un evento final de éxito o cancelación para la FSM superior.

CDoorMotor
  Abstracción del DRV8833.
  STBY, AIN1, AIN2, PWM, LEFT, RIGHT y STOP.

CDoorAngleSensor
  Wrapper conservador del AS5048A.
  Posición angular, velocidad y sensor_us.

CLedStrip
  FSM visual no bloqueante para WS2812B.

CLog
  Mensajes humanos, JSON de diagnóstico y salida Arduino Plotter.

CButton
  Lectura y antirebote no bloqueante del pulsador mediante CTimer.
  El objeto se crea en motorized_door.ino.

CTimer
  Base temporal no bloqueante del firmware.
```

`HOLDING` permanece reservado. El prototipo actual no tiene traba, solenoide, embrague ni mecanismo real de retención que permita validar ese estado de manera concluyente.

---

## FSM superior de demo

En `st_mode=0`, el arranque usa la posición absoluta del AS5048A:

```text
BOOT
  -> si ya está dentro de auto_tolerance_deg de POS_2: READY
  -> si está fuera: CENTERING -> POS_2 -> READY
```

Ciclo `fwd`:

```text
READY -> OPENING_FWD -> POS_1 -> OPEN_WAIT -> CLOSING_CENTER -> POS_2 -> READY
```

Ciclo `rew`:

```text
READY -> OPENING_REW -> POS_3 -> OPEN_WAIT -> CLOSING_CENTER -> POS_2 -> READY
```

`open_wait_ms` se carga desde NVS a la copia RAM de `CDoorConfig`. Al entrar en `OPEN_WAIT`, la FSM toma una copia del valor RAM y usa un `CTimer` creado en `motorized_door.ino`. No se agregó ningún `delay()` para el ciclo.

`stop` cancela el movimiento y el ciclo, deja el equipo en `STOPPED` y no inicia un retorno oculto. La recuperación explícita es mover a POS_2 con `go` o reiniciar en modo normal.

En `st_mode=100` no se ejecuta el centrado automático y se rechazan `fwd`/`rew`; siguen disponibles los comandos de diagnóstico.

### Estado DANGER

El pulsador se evalúa exclusivamente en el estado funcional de reposo:

```text
DEV_READY
puerta centrada en POS_2
motor detenido
LED azul respirando
```

Transición:

```text
DEV_READY + pulsación válida
  -> DEV_DANGER
  -> rojo intermitente durante danger_time_ms
  -> DEV_READY
```

Durante apertura, espera abierta, cierre, centrado o `STOPPED`, el pulsador no genera ninguna transición. `CButton` aplica el antirebote con su propio `CTimer`; el objeto `DangerButton` y el `dangerTimer` del estado se crean en `motorized_door.ino`.

El GPIO14 deja de ser consumido directamente por `CDoorMotion`: ya no cancela movimientos ni fuerza una alarma global. La decisión funcional pertenece únicamente a la FSM superior.

---

## Modos de movimiento

```text
motion_mode=0
  PWM fijo.
  Baseline para identificación de planta y diagnóstico.

motion_mode=1
  Perfil de aproximación no-PID.
  Usa boost inicial, zona lenta y PWM lento.

motion_mode=2
  Control de posición configurable P / PI / PD / PID.
  Default actual validado: P puro, Kp=0.7, Ki=0 y Kd=0.
```

El nombre histórico de algunas constantes todavía contiene `PD_POSITION`, pero `motion_mode=2` acepta las tres ganancias y el comportamiento efectivo depende de sus valores.

---

## FSM LED

Comportamiento de `v5.2a`:

```text
LED_STRIP_OFF
  Tira apagada.

LED_STRIP_IDLE
  Azul con respiración.

LED_STRIP_MOVING_FWD / LED_STRIP_MOVING_RWD
  Verde desplazándose durante apertura, centrado y movimientos directos.

LED_STRIP_OPEN_WAIT
  Verde fijo durante open_wait_ms.

LED_STRIP_CLOSING_FWD / LED_STRIP_CLOSING_RWD
  Rojo desplazándose durante el retorno a POS_2.

LED_STRIP_ARRIVED
  Conserva brevemente el último cuadro antes de volver a IDLE.

LED_STRIP_ALARM
  Rojo intermitente durante DEV_DANGER.
```

La FSM superior decide cuándo corresponde apertura, espera o cierre. `DoorMotion` y `DoorMotor` no conocen colores ni estados de producto.

Relación actual entre salida de motor y animación:

```text
DoorMotor RIGHT -> LED_STRIP_MOVING_RWD
DoorMotor LEFT  -> LED_STRIP_MOVING_FWD
```

La animación sigue el estado actual del motor. Por eso, durante el diagnóstico del tironeo, una inversión lógica del puente H también se veía como un cambio en el sentido visual de la tira.

---

## `led-sim`: simulación runtime

`led-sim` permite ejecutar el mismo firmware y el mismo camino de movimiento/LED reemplazando únicamente la lectura del AS5048A por una posición virtual.

Ejemplos:

```json
{"cmd":"led-sim","from":1,"to":2,"ms":700}
{"cmd":"led-sim","from":2,"to":3,"ms":850}
{"cmd":"led-sim","from":3,"to":1,"ms":950}
```

Cancelar:

```json
{"cmd":"led-sim-stop"}
```

Para probar sin movimiento físico:

```text
desconectar VM/6 V del motor
mantener ESP32, LED y sensor alimentados
mantener GND común
```

La simulación usa:

```text
DoorMotion normal
DoorMotor normal
FSM LED normal
transición ARRIVED normal
```

La única entrada reemplazada es la posición angular.

---

## Defaults compilados de `v5.2b`

Los siguientes valores quedan definidos en `door_config.h`:

```cpp
#define DOOR_POS_1_DEFAULT_DEG                  2.29f
#define DOOR_POS_2_DEFAULT_DEG                  291.23f
#define DOOR_POS_3_DEFAULT_DEG                  206.06f

#define DOOR_PWM_MOVE_DEFAULT                   80UL
#define DOOR_MOTION_MODE_DEFAULT                DOOR_MOTION_MODE_PD_POSITION

#define DOOR_PID_KP_DEFAULT                     0.70f
#define DOOR_PID_KI_DEFAULT                     0.00f
#define DOOR_PID_KD_DEFAULT                     0.00f
#define DOOR_PID_PWM_MAX_DEFAULT                80UL
#define DOOR_PID_PWM_MIN_EFFECTIVE_DEFAULT      70UL
#define DOOR_PID_MIN_EFFECTIVE_ERROR_DEFAULT    2.0f
#define DOOR_PID_I_ACTIVE_ERROR_DEFAULT         20.0f
#define DOOR_PID_INTEGRAL_LIMIT_DEFAULT         120.0f

#define DOOR_CONTROL_PERIOD_US_DEFAULT          5000UL
#define DOOR_AUTO_TOLERANCE_DEG_DEFAULT         2.00f
#define DOOR_AUTO_CROSS_MARGIN_DEG_DEFAULT      0.20f
#define DOOR_AUTO_MAX_RUN_MS_DEFAULT            10000UL
#define DOOR_AUTO_STALL_CHECK_MS_DEFAULT        250UL
#define DOOR_AUTO_MIN_MOVE_DEG_DEFAULT          0.30f
#define DOOR_AUTO_STALL_MAX_COUNT_DEFAULT       3UL
#define DOOR_AUTO_FINAL_SETTLE_MS_DEFAULT       80UL

#define DOOR_LED_ENABLED_DEFAULT                1UL
#define DOOR_LED_COUNT_DEFAULT                  8UL
#define DOOR_LED_BRIGHTNESS_DEFAULT             25UL
#define DOOR_LED_STEP_MS_DEFAULT                60UL
#define DOOR_LED_BREATH_MS_DEFAULT              25UL
#define DOOR_LED_BLINK_MS_DEFAULT               180UL

#define DOOR_OPEN_WAIT_MS_DEFAULT               2000UL
#define DOOR_OPEN_WAIT_MS_MAX                   60000UL
#define DOOR_DANGER_TIME_MS_DEFAULT             3000UL
#define DOOR_DANGER_TIME_MS_MAX                 60000UL

#define DOOR_LOG_LEVEL_DEFAULT                  DOOR_LOG_LEVEL_MSG
```

No se cambia `DOOR_CFG_SCHEMA_VERSION`.

Consecuencia:

```text
La configuración NVS existente se conserva.
Las claves nuevas usan sus defaults si todavía no existen:
  openwait=2000 ms
  dangertime=3000 ms
Al configurar open_wait_ms o danger_time_ms se actualizan RAM y NVS.
factory-reset carga y guarda todos los defaults.
```

---

## Comandos JSON

### Información

```json
{"info":"version"}
{"info":"all-params"}
```

### Ciclo automático de demo

```json
{"cmd":"fwd"}
{"cmd":"rew"}
{"open_wait_ms":2000}
{"danger_time_ms":3000}
```

`open_wait_ms` y `danger_time_ms` aceptan de 0 a 60000 ms y persisten en NVS.

### Movimiento real de diagnóstico

```json
{"cmd":"go","pos":1}
{"cmd":"go","pos":2}
{"cmd":"go","pos":3}
{"cmd":"stop"}
```

El `ack` confirma solamente que el pedido fue recibido. Al finalizar el
movimiento se emite un evento JSON separado:

```json
{
  "event":"motion-complete",
  "cmd":"go",
  "pos":2,
  "result":"ok",
  "reason":"posicion_alcanzada",
  "device_state":"READY",
  "final_deg":287.01,
  "target_deg":291.23
}
```

Los ciclos `fwd` y `rew` emiten `event:"cycle-complete"` al terminar el
regreso a POS_2 o al fallar. `all-params` incluye además `device_state` y
`current_deg` para sincronizar la aplicación al conectar.

### Simulación LED/movimiento lógico

```json
{"cmd":"led-sim","from":1,"to":2,"ms":700}
{"cmd":"led-sim","from":2,"to":3,"ms":850}
{"cmd":"led-sim","from":3,"to":1,"ms":950}
{"cmd":"led-sim-stop"}
```

### Posiciones

```json
{"pos1_deg":2.29}
{"pos2_deg":291.23}
{"pos3_deg":206.06}
```

### Modos y PWM

```json
{"motion_mode":0}
{"motion_mode":1}
{"motion_mode":2}

{"pwm_move":80}
{"pwm_start":80}
{"pwm_slow":60}
{"slow_zone_deg":20}
{"start_boost_ms":120}
```

### Control de posición

```json
{"pid_kp":0.7}
{"pid_ki":0}
{"pid_kd":0}
{"pid_pwm_max":80}
{"pid_pwm_min_effective":70}
{"pid_min_effective_error_deg":2}
{"pid_i_active_error_deg":20}
{"pid_integral_limit":120}
{"control_period_us":5000}
```

### Llegada y seguridad

```json
{"auto_tolerance_deg":2}
{"auto_cross_margin_deg":0.2}
{"auto_max_run_ms":10000}
{"auto_stall_check_ms":250}
{"auto_min_move_deg":0.3}
{"auto_stall_max_count":3}
{"auto_final_settle_ms":80}
```

### LED

```json
{"led_enabled":1}
{"led_enabled":0}
{"led_count":8}
{"led_brightness":25}
{"led_step_ms":60}
{"led_breath_ms":25}
{"led_blink_ms":180}
```

### Log y modo reservado

```json
{"log_level":0}
{"log_level":1}
{"log_level":2}
{"log_level":3}

{"st_mode":0}
{"st_mode":100}
```

`st_mode=0` habilita el centrado automático y los ciclos de demo. `st_mode=100` inicia detenido, evita movimientos automáticos al boot y mantiene disponibles `go`, `stop` y `led-sim`. Cambiar `st_mode` en runtime afecta los próximos comandos; el centrado de arranque se evalúa al reiniciar.

### Restaurar defaults

```json
{"cmd":"factory-reset"}
```

En `v5.2b`, `factory-reset` recupera el set validado, `open_wait_ms=2000`, `danger_time_ms=3000` y `st_mode=0`. No inicia un movimiento inmediatamente; el centrado normal se evalúa en el próximo reinicio.

---

## Serial Plotter

Activar salida compatible:

```json
{"log_level":3}
```

Variables actuales:

```text
travel
target
```

Volver a mensajes y respuestas JSON:

```json
{"log_level":1}
```

Para identificación de planta se usa `motion_mode=0`. Para comparar el control se repite el mismo recorrido cambiando solamente el modo o las ganancias.

Ejemplo de baseline:

```json
{"log_level":1}
{"led_enabled":0}
{"motion_mode":0}
{"pwm_move":70}
{"log_level":3}
{"cmd":"go","pos":3}
```

---

## Caso de estudio: motor nuevo y término D

Después de reemplazar el motor N20 apareció un tironeo visible tanto en la mecánica como en la animación LED.

El diagnóstico siguió esta secuencia:

```text
1. led-sim con VM desconectada:
   LED fluido; se descartó la FSM visual como causa autónoma.

2. movimiento real con LED apagado:
   el tironeo continuó; se descartó la carga de la tira.

3. revisión de masa y capacitor bulk de 220 µF:
   sin cambio relevante; la hipótesis de alimentación simple perdió fuerza.

4. motion_mode=0 con PWM fijo:
   movimiento suave; motor, reductora y driver podían trabajar sin tironeo.

5. Arduino Plotter con motion_mode=2 y Kd=0.05:
   se observó retroceso real cerca del objetivo.

6. motion_mode=2 con Kd=0:
   desaparecieron el tironeo mecánico y el salto visual.
```

Interpretación documentada:

```text
La salida de control podía cambiar de signo por acción de D.
El signo seleccionaba el sentido físico del puente H.
Una orden pequeña en sentido contrario era elevada al PWM mínimo efectivo 70.
La FSM LED seguía el estado actual del motor y mostraba la misma inversión.
```

La corrección estructural del término D queda diferida. El set operativo seguro y validado mantiene:

```text
pid_kd=0
```

Documentos asociados:

```text
doc/caso_estudio_I+D_motor_nuevo_PD_v1.pdf
doc/caso_estudio_I+D_motor_nuevo_PD_v1.docx
doc/anexo_relacion_tironeo_motor_animacion_led.pdf
doc/anexo_relacion_tironeo_motor_animacion_led.docx
```

---

## Reglas de trabajo sobre el prototipo

```text
No aplicar cargas laterales aleatorias al eje o cursor.
El juego visible del cursor 3D se acepta para esta etapa sin carga.
No modificar door_motion ni door_motor sin una necesidad clara.
No contaminar el control real del motor para implementar efectos visuales.
Mantener cambios pequeños, reversibles y medibles.
```

Si el conjunto mecánico vuelve a fallar, el próximo paso no será insistir con el mismo montaje: se evaluará un motor y acople más robustos, preparados para la carga real.

---

## Próximos pasos

Orden acordado después de validar `v5.2b-danger-button-fsm` en hardware:

```text
1. Validar DANGER únicamente en DEV_READY/POS_2.
2. Cerrar y etiquetar la FSM automática de demo con el evento de pulsador.
3. Mantener como evolución futura el tratamiento del evento en otros estados.
4. Migrar posteriormente a ESP-IDF/RTOS con productor de entrada y cola de eventos.
5. Mantener HOLDING y buzzer fuera hasta contar con hardware justificable.
6. Retomar beam_app sin mezclar sus cambios con el firmware.
```

El informe final presentará el prototipo como un proceso real de I+D, conectando electrónica, firmware, control automático, mecánica, instrumentación, programación, análisis de datos y gestión de riesgo técnico.

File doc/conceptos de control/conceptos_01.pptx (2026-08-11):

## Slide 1

Conceptos base de control

para la puerta motorizada

Clase de apoyo para leer la Etapa 2 y entender por qué aparece la necesidad de control realimentado.

PLANTA
FÍSICA

PWM

SENSOR

ERROR

PID

Objetivo didáctico: poner nombre a los fenómenos que ya aparecieron en las pruebas.

Materias: Sistemas de Control · Automatización · Programación Avanzada · Proyecto Final

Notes: Presentar esta clase como glosario técnico previo: sirve para que el alumno entienda target, error, cruce, stall, timeout, PWM fijo, approach y el puente conceptual hacia PID.

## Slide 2

1. Actuar no es controlar

El PWM mueve el motor, pero el sistema físico decide cómo responde

ESP32
firmware

DRV8833
puente H

Motor
N20

Puerta
/ carga

Sin realimentación, el firmware ordena una potencia y espera que la mecánica acompañe.

AS5048A
sensor

Con sensor, el sistema puede comparar lo que pidió contra lo que realmente pasó.

Materias: Electrónica de Potencia · Sistemas Embebidos · Sistemas de Control

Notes: Explicar que el puente H no “sabe” de posición: solo entrega energía en un sentido u otro. La realimentación aparece cuando el sensor cierra el ciclo.

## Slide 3

2. Posición, target y error

Tres palabras básicas para hablar de control de posición

Idea para explicar
• La posición actual viene del sensor.
• El target es la posición deseada.
• El error indica cuánto falta.
• El signo del error también indica de qué lado estamos.

actual

target

error = target − posición actual

Materias: Sistemas de Control · Sensores e Instrumentación · Programación

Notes: Usar la línea como analogía angular simplificada. Aclarar que en el firmware real hay normalización 0–360 y camino corto, pero para la explicación inicial alcanza con target, posición y error.

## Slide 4

2b. Ángulos circulares y wrap 0/360

El error angular debe calcularse por el camino corto, no por una resta directa

La posición angular no es una recta infinita: después de 359° vuelve a 0°.
• 0° y 360° representan la misma posición física.
• El firmware debe calcular el error considerando el camino corto.

No alcanza con target - actual

esp32-motorized-door-controller

IDEA CLAVE

actual 358° → target 2°

resta directa:
2 - 358 = -356°

0°/360°

actual = 358°

target = 2°

270°

90°

180°

camino corto:
+4°

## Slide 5

3. Tolerancia y llegada

En un mecanismo real no se exige error matemáticamente cero

target

zona
aceptable

Settle / estabilización
Después de frenar, se espera un instante para leer la posición final con menos movimiento residual.

Tolerancia
Rango donde el firmware acepta que la posición fue alcanzada.

Materias: Sistemas de Control · Mecánica · Sistemas Embebidos

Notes: Conectar con el prototipo: la tolerancia evita perseguir un cero irreal. El settle evita medir justo en el momento del frenado, cuando todavía hay inercia o juego.

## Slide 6

4. Cruce del objetivo y sobrepaso

A veces conviene detener aunque no se haya caído dentro de la tolerancia

Sobrepaso
La puerta sigue moviéndose por inercia después de que el firmware decidió cortar.
Cruce
La trayectoria pasó al otro lado del objetivo: es una señal útil para detener.

cruce

target

Materias: Mecánica · Sistemas de Control · Automatización

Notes: Explicar que el cruce no es un error de lectura: puede ser una estrategia de detección. El sobrepaso aparece por energía cinética, rozamiento y respuesta del mecanismo.

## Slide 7

5. Protecciones: stall, timeout y final de carrera

Llegar al target no es la única condición que debe vigilar el firmware

Mientras se mueve, el firmware debe mirar varias señales a la vez.

STALL

CANCELAR

AUTO
ACTIVO

TIMEOUT

FINAL
CARRERA

Stall: sin movimiento efectivo · Timeout: tiempo máximo · Final de carrera: límite físico · Cancelación: orden externa

Materias: Sistemas Embebidos · Automatización · Seguridad Funcional básica

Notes: Stall: se comanda el motor pero no cambia la posición. Timeout: nunca queda accionando para siempre. Final de carrera: señal física independiente. Cancelar: una orden externa siempre puede interrumpir.

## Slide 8

6. PWM fijo: una sola perilla, muchos compromisos

El primer control funciona, pero queda atado a la física

PWM 65

stalls

Conclusión técnica
Con lazo abierto no existe un único PWM que garantice arranque, precisión y robustez en todas las condiciones.

La carga puede ayudar a frenar el sobrepaso y, al mismo tiempo, hacer más difícil el arranque.

PWM 70

mínimo útil

más sobrepaso

PWM 75

PWM 80

demasiada energía

Materias: Sistemas de Control · Electrónica de Potencia · Ensayo experimental

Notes: Esta slide resume v3.1: PWM 65 falla, 70 es mínimo sin carga, 75/80 llegan pero se pasan. La carga no empeora todo linealmente: cambia la dinámica.

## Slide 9

7. Approach no-PID: mejorar sin formalizar todavía

Una estrategia empírica útil antes de pasar a control cerrado

boost de arranque

Aparecen más parámetros
• pwm_start
• start_boost_ms
• pwm_move
• slow_zone_deg
• pwm_slow
Sirven, pero dependen de la mecánica.

recorrido

zona lenta

Materias: Sistemas de Control · Automatización · Proyecto Final

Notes: Explicar el approach como puente: no es PID, no “piensa” con error/velocidad de forma formal. Se diseñan fases para vencer arranque y llegar con menos energía.

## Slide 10

8. Por qué aparece la necesidad de PD/PID

El ajuste empírico crece; el control cerrado ordena el problema

P empuja según cuánto falta.

D ayuda a frenar usando velocidad.

I corrige errores persistentes.

El objetivo no es “poner PID porque sí”.
Es pasar de perillas físicas a una ley de control basada en error, movimiento y evidencia.

error

P

D

I

Materias: Sistemas de Control · Análisis de datos · Proyecto Final

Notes: Aclarar que primero se puede probar P o PD. La I no siempre conviene; puede sumar sobrepaso si no se controla bien. El PID no reemplaza la validación física.

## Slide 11

9. Qué puede y qué no puede resolver un PID

El control mejora el comportamiento, pero no arregla por arte de magia la mecánica

Puede ayudar a
✓ repetir posiciones
✓ reducir sobrepaso
✓ ajustar potencia al error
✓ compensar variaciones moderadas
✓ llegar con menos golpes
✓ analizar la planta con datos

No debe usarse para tapar
✕ mala alineación
✕ juego mecánico excesivo
✕ motor insuficiente
✕ alimentación inestable
✕ falta de sensores de seguridad
✕ diseño mecánico débil

Regla práctica: primero validar la planta física; después sintonizar el controlador.

Materias: Sistemas de Control · Mecánica · Electrónica de Potencia · Proyecto Final

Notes: Esta slide es importante para no sobreprometer PID. El controlador es una herramienta; no reemplaza un buen mecanismo ni sensores de seguridad.

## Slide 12

10. Lectura de ingeniería

La medición entrega datos; el criterio técnico decide qué significan

observar

hipótesis

medir

decidir

La experiencia no reemplaza la medición: ayuda a convertirla en conocimiento de ingeniería.

Este es el puente entre la Etapa 2 y la identificación de planta.

Materias: Proyecto Final · Metodología de I+D · Sistemas de Control

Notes: Cerrar señalando que el recurso entrenado no “adivina”: observa, reconoce patrones, hace hipótesis razonables y decide cuál es la próxima prueba.

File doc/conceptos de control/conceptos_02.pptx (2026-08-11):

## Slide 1

Conceptos de control II

De la planta física al PID

Clase de apoyo antes de la Etapa 3: identificar la planta, simular y recién después tocar el firmware.

La idea central no es “poner PID” por costumbre. Primero se entiende cómo responde el sistema físico.

Planta

Medir

Modelo

Simular

PD/PID

Validar

esp32-motorized-door-controller

Conceptos II · 1

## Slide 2

Mapa conceptual

El puente entre la prueba de movimiento y el control formal

El estudiante debe poder explicar por qué cada paso existe: no se salta de “mueve” a “PID”; se construye evidencia.

1

2

3

4

5

Sistema real

motor + puerta + sensor

Ensayo

PWM fijo y medición

Modelo

aproximación matemática

Simulación

probar sin romper

Control

PD/PID conservador

esp32-motorized-door-controller

Conceptos II · 2

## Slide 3

¿Qué es una planta?

El objeto físico que responde a nuestras órdenes

En este proyecto, la planta no es solo el motor. Incluye reductora, acople, puerta/aguja, rozamiento, juego mecánico, carga y alimentación.

perturbaciones: fricción · carga · backlash · tensión · desgaste

PWM

DRV8833

Motor + reductora

Mecanismo / puerta

Sensor AS5048A

Planta física

esp32-motorized-door-controller

Conceptos II · 3

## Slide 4

Entrada, salida y variables

Para controlar primero hay que nombrar qué entra y qué sale

Cadena conceptual: PWM → velocidad → posición. El sensor mide la salida; el controlador decide la siguiente acción.

Entrada
PWM aplicado al puente H
Sentido de giro
Tiempo de activación

Planta
Motor N20 + reductora
Mecanismo de puerta
Rozamiento e inercia

Salida
Posición angular
Travel del recorrido
Velocidad estimada

ACTUACIÓN

SISTEMA FÍSICO

MEDICIÓN

esp32-motorized-door-controller

Conceptos II · 4

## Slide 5

¿Por qué identificar la planta?

Medir antes de diseñar el controlador

Identificar la planta significa aplicar entradas conocidas y registrar la respuesta real.
En Step8F se usó motion_mode=0 y PWM fijo para no contaminar la medición.

No alcanza con decir:
“PWM 70 mueve”.
Hay que saber cuánto mueve, cuándo despega, con qué velocidad y cómo cambia al subir PWM.

PROBLEMA

CRITERIO

Una variable controlada por vez

esp32-motorized-door-controller

Conceptos II · 5

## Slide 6

Ensayo de identificación

Entrada fija, medición temporal y zona útil

En el informe, cada muestra del Plotter representa aproximadamente 0,05 s. La velocidad útil se calculó en la zona central de la curva, evitando arranque y llegada.

motion_mode = 0 · PWM = 70 / 75 / 80 · travel vs tiempo

1

2

3

4

5

PWM fijo

Mover

Medir travel

Estimar velocidad

Ajustar modelo

esp32-motorized-door-controller

Conceptos II · 6

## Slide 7

Arranque, régimen y llegada

No toda la curva representa lo mismo

travel

tiempo

Arranque
fricción estática
retardo posible

esp32-motorized-door-controller

Régimen útil
pendiente casi constante
velocidad estimable

Llegada
inercia + corte
error final

Conceptos II · 7

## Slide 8

Zona muerta y fricción estática

Puede haber PWM aplicado sin movimiento visible

Zona muerta
El motor recibe energía, pero la planta todavía no se mueve.
Puede aparecer por fricción estática, juego, zona dura o torque insuficiente.

Ejemplo Step8F: con PWM 70, un sentido tuvo un retardo de arranque cercano a 0,95 s aunque luego la velocidad útil fue normal.

CONCEPTO

PWM_dead

PWM

esp32-motorized-door-controller

Conceptos II · 8

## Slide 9

Modelo lineal simple

Una primera aproximación suficiente para simular

velocidad_deg_s = Kv · ( PWM − PWM_dead )
travel(t) = ∫ velocidad_deg_s dt

Modelo identificado
velocidad_deg_s ≈ 4,97 · ( PWM − 18 )

velocidad

Promedio medido vs modelo

80

75

70

PWM

esp32-motorized-door-controller

Conceptos II · 9

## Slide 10

Modelo ≠ realidad

El modelo sirve aunque no capture todo

I+D: un buen modelo no es una copia perfecta. Es una herramienta para decidir mejor la próxima prueba.

Lo que captura
• velocidad aproximada en régimen
• efecto principal del PWM
• zona muerta promedio
• relación entrada → salida

Lo que puede no capturar
• juego mecánico
• retardo puntual de arranque
• ruido del sensor
• desgaste
• cambios de carga o rozamiento

ÚTIL

LÍMITE

esp32-motorized-door-controller

Conceptos II · 10

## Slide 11

¿Por qué simular antes de tocar firmware?

Proteger la baseline y probar escenarios

Simular permite encontrar una zona razonable de parámetros antes de arriesgar el prototipo físico. No reemplaza la validación: la prepara.

Firmware validado
no se toca

Modelo de planta
PWM → velocidad → travel

Simulación Python
Kp, Ki, Kd, saturación

Constantes iniciales
conservadoras

esp32-motorized-door-controller

Conceptos II · 11

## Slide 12

Realimentación

Medir, comparar y corregir en cada ciclo

El sistema ya no actúa a ciegas: usa la diferencia entre lo deseado y lo medido.

target
posición deseada

Σ

error

Controlador
P / PD / PID

Planta
puerta real

sensor
posición medida

esp32-motorized-door-controller

Conceptos II · 12

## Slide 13

P, D e I

Tres acciones distintas dentro del controlador

PWM_control = Kp·error + Ki·integral − Kd·velocidad

P · Proporcional
Empuja según el error.
Error grande → más acción.
Cerca del objetivo → menos acción.

P

D · Derivativo
Actúa como amortiguación.
Si la puerta llega rápido, ayuda a frenar antes.

D

I · Integral
Corrige errores persistentes acumulados.
Útil cerca del punto, peligrosa si acumula de más.

I

esp32-motorized-door-controller

Conceptos II · 13

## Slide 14

Saturación, windup y anti-windup

El PID real necesita límites

Un PID sin restricciones no es automáticamente un buen controlador

Saturación
El controlador puede pedir más PWM del que el sistema debe aplicar.
Ejemplo: pedir 130, pero limitar a 80.

esp32-motorized-door-controller

LÍMITE FÍSICO

Windup
La integral sigue acumulando error aunque la salida esté saturada.
Al salir de saturación puede provocar sobrepaso.

RIESGO

Anti-windup
Limitar la acumulación, habilitar I solo en cierta zona o frenarla cuando el control satura.

PROTECCIÓN

Conceptos II · 14

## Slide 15

¿Por qué empezar con PD?

Una decisión conservadora para este mecanismo

La pregunta de ingeniería no es “¿podemos poner PID?”. Es “¿qué parte del controlador necesita realmente esta planta?”.

Primero PD
Kp empuja hacia el objetivo.
Kd amortigua la llegada usando velocidad.
Ki queda en cero al inicio.

PASO 1

Después evaluar I
Solo si queda error persistente.
Con anti-windup.
Preferentemente cerca del objetivo y sin saturación.

PASO 2

esp32-motorized-door-controller

Conceptos II · 15

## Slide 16

Puente hacia la Etapa 3

Ahora sí: identificación de planta y preparación del PD/PID

Cierre conceptual: la planta se mide, el modelo se simula y el controlador se prueba con prudencia. Ese es el camino de I+D antes de exigirle al prototipo real.

Medir
PWM fijo
travel vs tiempo

Identificar
Kv y PWM_dead
modelo simple

Simular
Python
Kp, Kd, Ki

Implementar
motion_mode=2
conservador

Validar
hardware real
comparar curvas

esp32-motorized-door-controller

Conceptos II · 16

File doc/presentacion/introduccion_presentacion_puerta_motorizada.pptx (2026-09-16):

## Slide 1

Del prototipo funcional a una arquitectura medible, controlable y operable.

Presentación

Puerta motorizada
de paso

Estrategia de desarrollo de un proyecto real de I+D aplicado como trabajo práctico integrador de Ingeniería Electrónica.

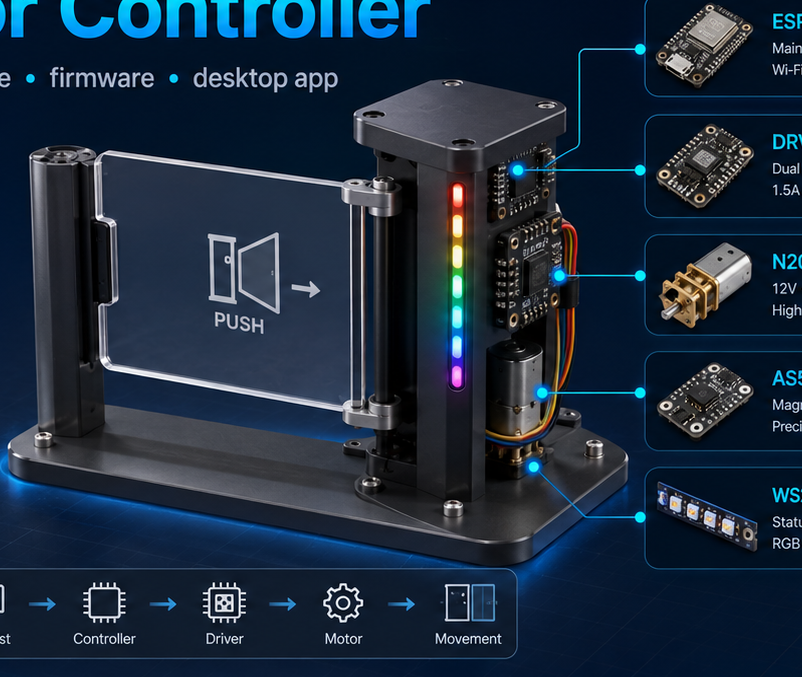
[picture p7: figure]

Mecánica

Electrónica

Firmware

Control

No mostrar solamente el resultado final, sino el proceso: decisiones de diseño, ensayos, problemas, retrocesos y construcción progresiva de una base técnica confiable.

Idea central

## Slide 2

1. Punto de partida: un requerimiento real

El trabajo nace de una necesidad de producto y se transforma en una experiencia de I+D a escala.

Puerta motorizada de paso para control de acceso

Diseño elegante para edificios y espacios de alta categoría.

Apertura automática y movimiento controlado de la hoja.

Indicadores luminosos asociados al tránsito y al estado.

Una solución mecatrónica donde mecánica, electrónica y software deben convivir.

REQUERIMIENTO

La referencia sirve para definir el tipo de producto; el objetivo académico es reproducir funciones esenciales y recorrer el proceso de desarrollo.

Referencia visual y funcional

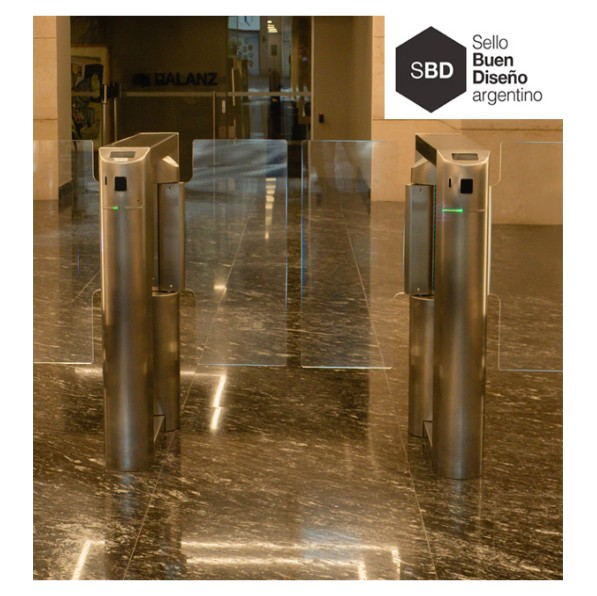
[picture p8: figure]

El proyecto no busca copiar una puerta comercial: busca aprender cómo se construye una solución técnica justificable.

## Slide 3

2. Objetivo del trabajo práctico integrador

Construir un prototipo funcional a escala que permita experimentar, medir y tomar decisiones de ingeniería.

Desarrollar una puerta motorizada de paso con señalización luminosa capaz de reproducir las funciones esenciales del producto real.

Prototipo funcional

Movimiento físico reproducible sobre una maqueta a escala.

1

Posición y control

Medición de posición, error, sobrepaso y estrategias de control.

2

Señalización

Indicadores luminosos vinculados al estado y al movimiento.

3

Operación y diagnóstico

Comandos, configuración, monitoreo y herramientas de prueba.

4

Diseñar, construir, programar, experimentar, validar y justificar decisiones frente a un problema abierto de I+D.

Competencia profesional buscada

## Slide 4

3. Una integración real de competencias

El valor del proyecto está en la interacción entre áreas, no en estudiar cada disciplina de manera aislada.

Diseño + fabricación 3D

estructura, puerta, soportes, mecanismos

1

Hardware

controlador, driver, motor, sensor, LED y seguridad

2

Firmware

drivers, comandos, máquinas de estados y configuración

3

Automatización

tareas concurrentes, temporización y respuesta segura

4

Sistemas de control

planta, realimentación, P / PD / PID y validación

5

Aplicación

operación, configuración, visualización y diagnóstico

6

La puerta obliga a integrar hardware, software y mecánica dentro de un único sistema observable.

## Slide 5

4. Preguntas que guían el proyecto

Las decisiones de control se plantean como preguntas verificables, no como una receta predeterminada.

¿Qué problemas busca resolver un controlador PID en una puerta motorizada real?

1

¿Hasta qué punto puede verificarse funcionalmente el uso del PID mediante el prototipo 3D a escala?

2

¿Qué resultados del prototipo pueden transferirse al producto real y cuáles deben validarse nuevamente?

3

Variables observadas durante los ensayos

posición angular

error de posición

tiempo

sobrepaso

señal de control

repetibilidad

carga / rozamiento / sentido

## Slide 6

5. Estrategia de desarrollo: avanzar sobre evidencia

Primero se valida una base mínima; después se agregan complejidad y nuevas preguntas sin perder lo que ya funciona.

Mecánica

¿Se puede mover físicamente?

1

Componentes

¿Cada parte funciona por separado?

2

Firmware

¿Podemos comandar y medir?

3

Arquitectura

¿Podemos evolucionar sin romper?

4

Control

¿Podemos mejorar el comportamiento?

5

Aplicación

¿Podemos operar y diagnosticar?

6

→

→

→

→

→

Una nueva prueba puede revelar una limitación mecánica, electrónica o de software y obligar a revisar decisiones anteriores. Por eso se conservan versiones funcionales como puntos de referencia.

I+D no lineal

medir → interpretar → decidir → probar de nuevo

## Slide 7

6. Qué puede validar la maqueta - y qué no

La escala reducida acelera el aprendizaje, pero no reemplaza la validación de un producto industrial.

Principios funcionales del movimiento.

Integración entre hardware, firmware y mecánica.

Lectura de posición y comportamiento del control.

Coordinación de tareas, comandos y señalización.

Repetibilidad y respuesta ante cambios de carga.

SE PUEDE VALIDAR

DEBE VALIDARSE NUEVAMENTE

Dimensiones y materiales de la puerta real.

Resistencia estructural y desgaste.

Seguridad de personas y normativa aplicable.

Tolerancias de fabricación y montaje.

Durabilidad y comportamiento en uso prolongado.

La maqueta permite aprender y descartar hipótesis con bajo costo; no certifica la puerta final.

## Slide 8

7. Recorrido de la serie

La presentación fija el problema. Los conceptos explican las herramientas. Las etapas muestran cómo se aplicaron.

Etapa 1

Validación de hardware
y firmware monolítico

Etapa 2

Arquitectura modular
y control configurable

Etapa 3

Identificación de planta
e instrumentación

Etapa 4

Simulación y
validación PID

Etapa 5

Cambio de motor,
diagnóstico y mejoras

Etapa 6

Aplicación de escritorio
y operación integral

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
El material queda organizado como una historia técnica: problema → fundamentos → evidencia → arquitectura → resultado.

PRESENTACIÓN

→

CONCEPTOS DE CONTROL

→

ETAPAS 1 - 6

→

FSM / ARQUITECTURA

→

CONCLUSIONES

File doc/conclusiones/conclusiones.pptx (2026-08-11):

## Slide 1

Conclusiones y próximos pasos

Del prototipo funcional a escala al comienzo de un proyecto profesional


I+D · aprendizaje aplicado · ingeniería de producto

esp32-motorized-door-controller · conclusiones

1

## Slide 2

1. Lo que realmente quedó demostrado

No fue “hacer girar un motor”: fue construir una cadena técnica verificable.

El prototipo impreso en 3D pudo mover la puerta y leer posición absoluta.

El firmware dejó de ser monolítico y pasó a módulos con responsabilidades claras.

El PWM fijo mostró límites; la planta se midió; la simulación orientó el ajuste.

El caso motor nuevo + LED mostró cómo aislar variables y revisar hipótesis.

La app expuso operación, diagnóstico y configuración sin reemplazar la lógica del firmware.

La instrumentación entrega datos. El criterio técnico decide qué significan y qué prueba sigue.

1

Hardware y mecánica

2

Arquitectura

3

Control

4

Diagnóstico

5

Producto

esp32-motorized-door-controller · conclusiones

2

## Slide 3

2. El recorrido importó tanto como el resultado

Cada etapa dejó una baseline y una razón para avanzar.

Este orden evitó saltar directo a PID, app o producto sin entender primero la planta real.


esp32-motorized-door-controller · conclusiones

3

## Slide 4

3. La arquitectura fue una herramienta de I+D

No fue prolijidad estética: permitió probar, aislar y volver atrás sin perder lo validado.

Arquitectura escalable = capacidad de investigar sin destruir la evidencia anterior.


Qué habilitó

mantener motion_mode=0 como baseline

cambiar estrategias sin reescribir todo

simular movimiento de LED sin motor real

separar comunicación, memoria y FSM

diagnosticar fallas por comparación

•

•

•

•

•

esp32-motorized-door-controller · conclusiones

4

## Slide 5

4. Control: la pregunta no es “¿tiene PID?”

La pregunta correcta es: ¿qué necesita esta planta para comportarse bien?

La simulación estuvo cerca porque antes se hizo bien el trabajo: identificar la planta, simular y conservar baseline.

Próxima decisión técnica: qué hacer definitivamente con D en esta planta y cómo justificarlo con medición.

PWM fijo

mueve, pero depende de carga, sentido e inercia

Approach

mejora arranque, pero aumenta parámetros empíricos

Planta

medir antes de ajustar: PWM → velocidad → travel

Simulación

reduce búsqueda, no reemplaza el hardware

Control real

la evidencia posterior simplificó a P

1

2

3

4

5

esp32-motorized-door-controller · conclusiones

5

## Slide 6

5. El software mínimo ya no es una sola FSM

Dispositivo, posicionamiento y LED conviven en un superloop cooperativo.

Lección: el paralelismo útil no es “todo al mismo tiempo”, sino estados independientes actualizados sin bloquear.


FSM superior

decide qué estados del producto son válidos

DoorMotion

ejecuta target, control, llegada, stall y settle

LedStrip

muestra estado y sentido sin bloquear

Switch DANGER

evento aceptado solo cuando la FSM superior lo permite

esp32-motorized-door-controller · conclusiones

6

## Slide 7

6. La app abre el primer frente de producto

Ya no alcanza con que el firmware funcione: el operador necesita interpretar, configurar y diagnosticar.


La app debe seguir los estados reales del firmware, no inferirlos por intuición.

esp32-motorized-door-controller · conclusiones

Pendiente inmediato: corregir comportamientos ante desconexión y recuperación.

7

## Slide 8

7. Próxima etapa técnica

Lo que sigue ya no es “agregar una feature”: es empezar a acercarse a ingeniería de producto.

Control

decidir qué hacer con D y cómo demostrarlo

1

App

robustecer desconexión, estados y recuperación

2

Escala real

prototipo representativo y verificación del controlador

3

Mecánica

embrague, solenoide y bloqueo si debe impedir paso

4

Hardware

nuevo controlador, protecciones, conectores, PCB

5

Costo

BOM real, proveedores, montaje, repetibilidad

6

esp32-motorized-door-controller · conclusiones

8

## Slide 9

8. Escala real: cambia la planta

El mini modelo valida el camino; una puerta real agrega masa, rozamiento, tolerancias y seguridad.

La sintonía real se vuelve una decisión de población de plantas, no de una unidad aislada.

Mini prototipo

motor N20 pequeño

cargas acotadas

piezas impresas

sin embrague ni traba real

gran valor para aprender y validar arquitectura

Equipo real

motor/eje/acople dimensionados

puerta, rodamientos y estructura

variaciones entre unidades

BOM, proveedores y procesos

seguridad mecánica y normativa

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
esp32-motorized-door-controller · conclusiones

9

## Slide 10

9. Prototipo no es producción

El entusiasmo construye el primer prototipo; la disciplina industrial sostiene el producto.

En experiencia real, llevar un equipo a producción puede tomar años.

Un equipo de 6 personas con experiencia puede pasar largos ciclos resolviendo detalles de fabricación, proveedores, tooling, repetibilidad, pruebas y documentación.

A veces el desafío no es diseñar la pieza: es fabricar la pieza correcta cuando el proveedor intenta llevarte a la pieza que a él le conviene.

Prototipo

funciona una vez

Pre-serie

funciona muchas veces

Producción

funciona repetible, seguro y costo viable

→

→

esp32-motorized-door-controller · conclusiones

10

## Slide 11

10. Las partes que vienen pesan más

Cuando se acerca el producto real, crece la presión y bajan los márgenes para improvisar.

El proyecto académico muestra el camino. El proyecto profesional exige repetirlo con evidencia, seguridad y escala.

Presión técnica

seguridad de personas

fallas repetibles

ensayos formales

documentación y trazabilidad

BOM y costo objetivo

Presión industrial

proveedores y fabricación

jigs / fixtures de test

firmware actualizable

tolerancias mecánicas

criterio de aceptación

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
esp32-motorized-door-controller · conclusiones

11

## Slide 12

Conclusión final

No cerramos un producto. Construimos una base seria para empezar uno.

que la plataforma puede moverse, medirse y configurarse.

que la planta real manda sobre la teoría.

que arquitectura y modos de prueba aceleran el diagnóstico.

el camino hacia escala real, seguridad, BOM y producción.

Recién empieza.

Se validó

Se aprendió

Se demostró

Se abrió

esp32-motorized-door-controller · conclusiones

12

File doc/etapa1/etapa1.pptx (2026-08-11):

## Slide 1

Etapa 1

Validación inicial de hardware
y plataforma electromecánica

Del diseño CAD a la primera plataforma física gobernada por firmware

CAD / 3D

Hardware

6 V directo

Firmware

Ensayo PWM

1

2

3

Primero se validó la física: diseño 3D, montaje, selección de componentes y prueba directa del N20 a 6 V. Luego se integró el hardware y se desarrolló un primer firmware monolítico para mover, medir y observar el sistema.

Resultado: plataforma operativa + primer aprendizaje de control.

RESUMEN DE LA ETAPA

4

5

Materias: Sistemas de Representación · Electrónica I/II/III · Automatización · Fundamentos de Programación · Programación Avanzada · Sistemas de Control · Proyecto Final

esp32-motorized-door-controller

Etapa 1 · 1

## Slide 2

1. Diseño mecánico previo

El primer riesgo era que el mecanismo simplemente no pudiera moverse

Ensamblaje CAD utilizado para verificar posiciones, soportes, amure del motor y espacio para los componentes.

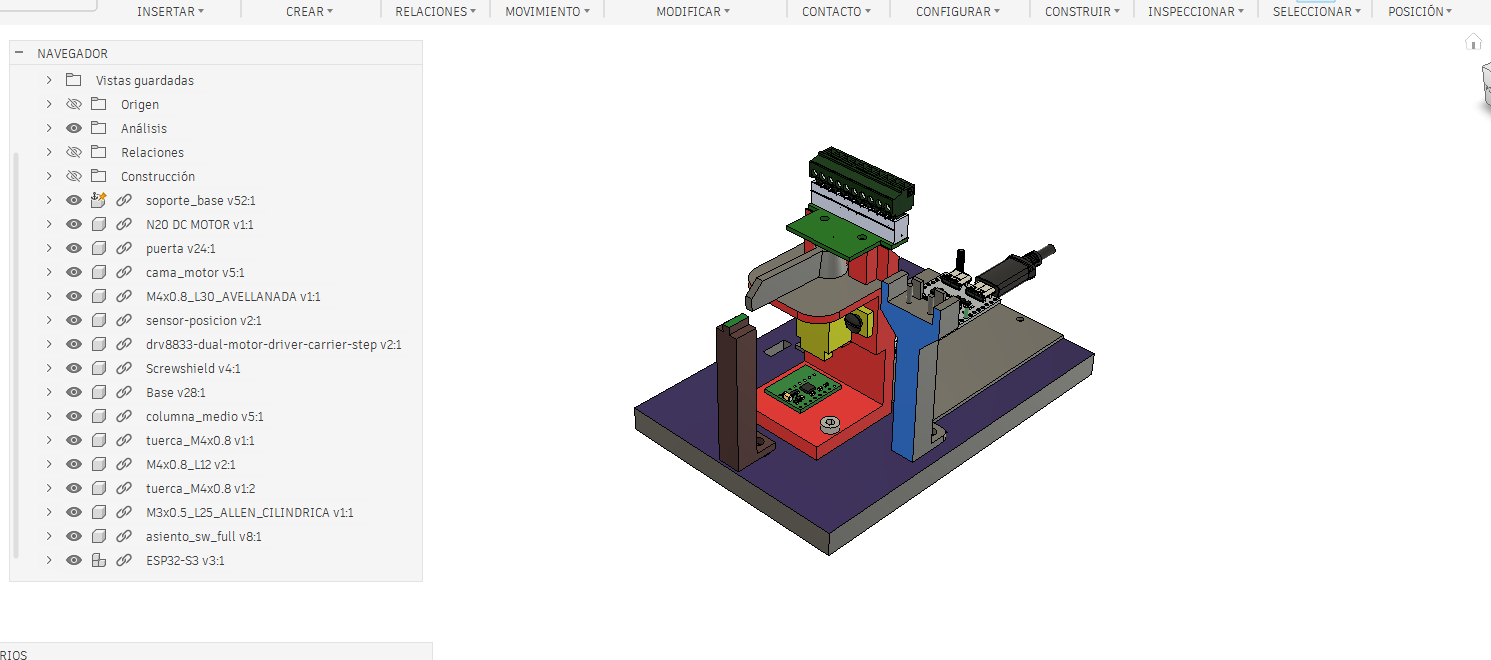
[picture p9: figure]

Motor centrado + mecanismo libre + puerta/aguja montable

• Modelado de base, soporte de motor, puerta, sensor, switch y fijaciones.
• El amure y el centrado son críticos: una desalineación agrega rozamiento y esfuerzos laterales.
• La impresión 3D permite iterar rápido, pero cada cota crítica debe validarse sobre el montaje real.

HITO MECÁNICO

Materias: Sistemas de Representación · Modelado/Fabricación 3D · Automatización

esp32-motorized-door-controller

Etapa 1 · 2

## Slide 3

2. Hardware y esquemático completo

Probar por partes no significa diseñar sin una arquitectura documentada

Esquemático de referencia: incluso usando módulos comerciales, conviene documentar la arquitectura completa.

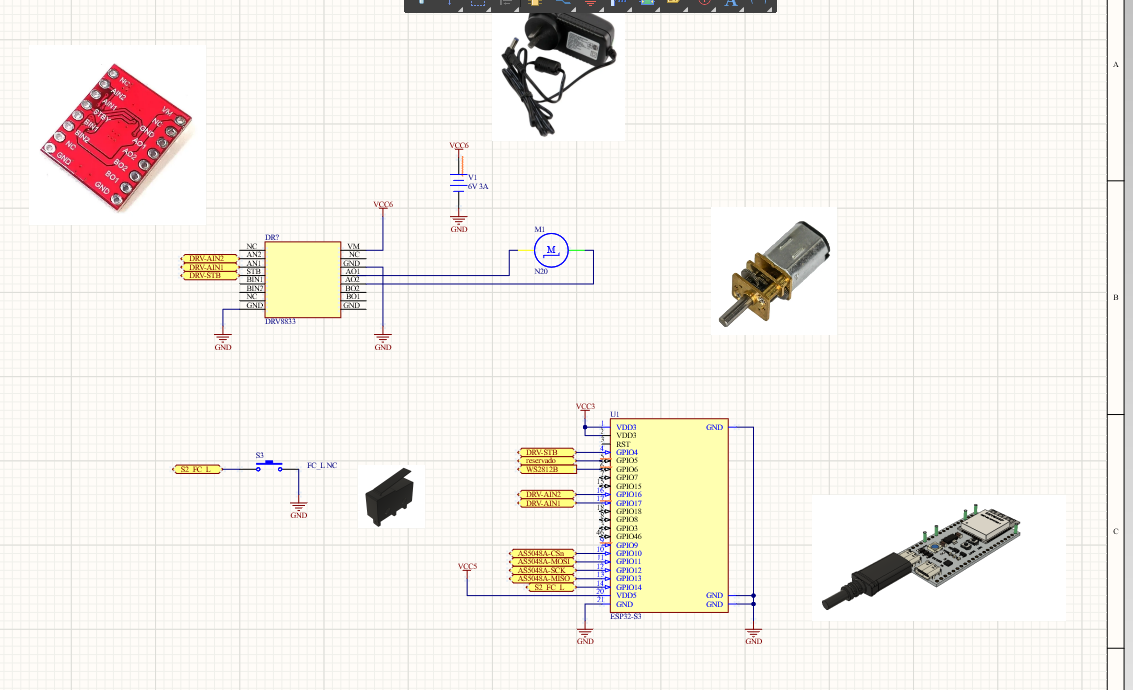
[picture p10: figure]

• ESP32-S3 + DRV8833 + motor N20 6 V.
• AS5048A para posición absoluta y final de carrera como entrada adicional.
• Fuente de 6 V y masa común documentadas desde el inicio.
• El montaje con módulos es prototipo; el esquemático es la base del futuro PCB del producto.

BUENA PRÁCTICA

Materias: Electrónica I, II y III · Sistemas de Representación · Proyecto Final

esp32-motorized-door-controller

Etapa 1 · 3

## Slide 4

3. BOM aproximado de la plataforma inicial

Lista preliminar obtenida del ensamblaje 3D y del esquemático

• Base y soporte principal
• Cama de motor
• Puerta / aguja
• Soporte de sensor
• Asiento de switch
• Fijaciones M3 / M4

• ESP32-S3 Dev Module
• DRV8833
• Motor N20 6 V
• AS5048A
• Final de carrera
• Fuente 6 V

• Screw shield / adaptador
• Cableado
• Tira WS2812B prevista
• Tornillería
• Conectores
• Elementos impresos 3D

Mecánico

Electrónico

Integración

El BOM todavía no es de producción: sirve para documentar la plataforma y detectar dependencias tempranas entre mecánica, electrónica y montaje.

Materias: Electrónica I/II/III · Sistemas de Representación · Automatización · Proyecto Final

esp32-motorized-door-controller

Etapa 1 · 4

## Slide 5

4. Primera condición de validación

Antes del firmware: demostrar que el conjunto mecánico realmente funciona

1

Imprimir y montar

2

N20 a 6 V

3

Girar ambos sentidos

4

Montar puerta/aguja

5

Integrar electrónica

El motor debe quedar centrado, girar libremente en ambos sentidos y transmitir el movimiento a la puerta sin interferencias críticas.

Esta prueba parece simple, pero descarta un riesgo capaz de invalidar todas las etapas posteriores.

Condición de avance

Materias: Automatización · Sistemas de Representación · Electrónica I/II/III · Proyecto Final

esp32-motorized-door-controller

Etapa 1 · 5

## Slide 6

5. Primer firmware monolítico

Una herramienta de validación física, no todavía una arquitectura de producto

Un único .ino, sin capas ni abstracciones de dominio.

• Motor, sensor, comandos Serial, posiciones, diagnóstico y control automático conviven en el mismo archivo.
• Los “estados” aparecen mediante enums, flags y funciones; no existe una FSM central formal.
• Se utilizó asistencia de Codex para acelerar la iteración; la validación real se hizo sobre el hardware.
• Es apropiado para probar rápido. Se vuelve costoso de mantener cuando el producto empieza a crecer.

IDEA CENTRAL

void loop() {
readSerialCommands();

if (autoMoveActive) {
updateAutoMove();
return;
}

checkMotorTimeout();

if (streamEnabled &&
millis() - lastStreamMs >= STREAM_PERIOD_MS) {
lastStreamMs = millis();
readSensorDegMeasured(false);
printSensor();
}
}

Lectura: el loop coopera; durante el automático ejecuta una actualización periódica y vuelve a iterar.

loop() real simplificado

Materias: Fundamentos de Programación · Programación Avanzada · Automatización

esp32-motorized-door-controller

Etapa 1 · 6

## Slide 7

6. Flujo funcional del firmware monolítico

Representación didáctica de estados implícitos; no es una FSM formal por switch-case

PULSO
LEFT

cmd f/F

AUTO
FINISH

timeout / stop

SETUP

tolerancia / cruce

Estado implícito

autoMoveActive
motorState
autoDirection

IDLE /
LISTO

cmd 1/2/3

AUTO
START

elige dirección

AUTO
ACTIVO

FC_L / timeout /
stall / x

AUTO
CANCEL

timeout / stop

PULSO
RIGHT

cmd r/R

leer sensor → error → condiciones

cada ~5 ms

Materias: Programación Avanzada · Fundamentos de Programación · Automatización

esp32-motorized-door-controller

Etapa 1 · 7

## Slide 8

7. Qué representa este primer firmware

La falta de abstracciones es deliberada: primero validar; después organizar

• Probar motor, sensor y comandos rápidamente.
• Medir el comportamiento real del mecanismo.
• Aislar si un problema es físico, eléctrico o de software.
• Crear una baseline funcional antes de refactorizar.

• Separación clara entre motor, sensor, control y producto.
• Escalabilidad al sumar LED, configuración persistente y app.
• Reutilización sencilla de componentes.
• Trazabilidad de responsabilidades cuando el sistema crece.

SIRVE PARA

NO RESUELVE

Decisión de I+D: no descartar lo que funciona; conservarlo como baseline y evolucionar sobre evidencia.

Materias: Programación Avanzada · Proyecto Final · Automatización

esp32-motorized-door-controller

Etapa 1 · 8

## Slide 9

8. Ensayo v3.1: PWM fijo y carga

El problema deja de ser “mover un motor” y pasa a depender de la planta física

Una sola perilla parece simple…

3 stalls · no confiable en LEFT

mínimo confiable sin carga

llega, pero aumenta el sobrepaso

más sobrepaso; no mejora precisión

No existe un único PWM que garantice arranque, precisión y robustez en todas las condiciones.

La carga cambia la dinámica; no simplemente “empeora”

La carga puede reducir el sobrepaso en algunos recorridos y, al mismo tiempo, aumentar el riesgo de no arrancar.

Fuente técnica: informe de ensayo v3.1.

PWM FIJO

EFECTO DE CARGA

PWM 65

Carga

0 g

Mov.

12

Stalls

0

Error prom.

2.51°

Error máx.

4.00°

PWM 70

PWM 75

2 g

18

2

1.80°

3.65°

PWM 80

8 g

10

1

1.41°

3.30°

Materias: Sistemas de Control · Automatización · Proyecto Final

esp32-motorized-door-controller

Etapa 1 · 9

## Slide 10

9. Qué demostró la instrumentación

El sistema detecta el objetivo a tiempo; el error final aparece después del corte

Período de control

Se cumple el ciclo nominal

Muestra máx.

Variación temporal muy baja

Lectura AS5048A

SPI rápido frente al ciclo

Cálculo/control

Muy por debajo de 5 ms

Conclusión: no hay evidencia de pérdida de posición por CPU, SPI ni Serial. El problema dominante es mecánico/dinámico.

5000 µs

5002–5006 µs

~31 µs

38–44 µs

Fuente técnica: informe de ensayo v3.1 — mediciones de muestreo, sensor, control y error final.

EVIDENCIA CLAVE

decision_error_deg

cerca del target

final_error_deg

puede quedar desplazado

Materias: Sistemas Embebidos · Electrónica · Sistemas de Control · Proyecto Final

esp32-motorized-door-controller

Etapa 1 · 10

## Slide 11

10. Decisión de continuidad

Antes de modularizar: conservar la baseline y probar una mejora de control por vez

1

2

3

4

Baseline v3.1

PWM fijo medido
y conservado

Boost de arranque

PWM alto por
un tiempo breve

Llegada con menos energía

Reducir PWM /
pre-corte o frenado

PD/PID

Realimentación con
AS5048A

La v3.1 confirma que el problema ya no es de lectura ni de muestreo, sino de control dinámico. La siguiente evolución debe cambiar una sola variable, medir el efecto y conservar siempre la baseline funcional.

Criterio del informe: “antes de modularizar”, ensayar una v3.2 mínima con una única mejora de control.

Materias: Proyecto Final · Sistemas de Control · Programación Avanzada · Automatización

esp32-motorized-door-controller

Etapa 1 · 11

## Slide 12

11. La experiencia también forma parte del método

Los datos son necesarios; saber qué observar y qué pregunta hacer también.

Estas conclusiones no aparecen solas.
Surgen de un recurso técnico entrenado que puede relacionar lo que observa con PWM, puente H, firmware y dinámica mecánica.

• La experiencia orienta qué variable conviene medir.
• El conocimiento previo permite formular hipótesis útiles.
• La prueba controlada transforma la intuición en evidencia.

DEL SÍNTOMA A LA DECISIÓN

El instrumento entrega datos.
El criterio técnico decide qué significan y qué prueba sigue.

IDEA CENTRAL

OBSERVAR

INTERPRETAR

HIPÓTESIS

MEDIR

DECIDIR

La experiencia no reemplaza la medición: ayuda a convertirla en conocimiento de ingeniería.

Materias: Proyecto Final · Sistemas de Control · Electrónica · Programación Avanzada · Automatización

Etapa 1 · 12

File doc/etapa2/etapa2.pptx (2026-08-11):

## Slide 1

Arquitectura modular
y control configurable

De la baseline monolítica a una base escalable y al perfil approach no-PID

Se conserva el comportamiento físico validado y se separan responsabilidades entre configuración, posicionamiento y acceso al hardware.
Luego se incorpora un perfil approach no-PID configurable, sin perder el baseline de PWM fijo.

Resultado: el software escala mejor; el control empírico revela sus propios límites.

Materias: Programación Avanzada · Sistemas de Control · Automatización · Proyecto Final

Etapa 2

Modularizar

FSM explícita

Config JSON/NVS

Approach no-PID

Medir límites

1

2

3

RESUMEN DE LA ETAPA

4

5

esp32-motorized-door-controller

Etapa 2 · 1

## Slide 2

1. ¿Por qué modularizar?

El firmware monolítico ya cumplió su función: validar rápido y producir evidencia

Decisión de I+D: refactorizar sin “mejorar” todavía la física. Primero separar responsabilidades y comprobar que el baseline se conserva.

Materias: Programación Avanzada · Proyecto Final · Automatización

Lo que NO se toca

• Pines y sentidos ya validados.
• Criterios de llegada, cruce, stall y timeout.
• Período de control y mediciones existentes.
• PWM fijo como referencia de comportamiento.

Lo que ya no escala

• Comunicación, parámetros, movimiento y hardware mezclados en el .ino.
• Cada nueva función aumenta dependencias y riesgo de regresión.
• Resulta difícil cambiar una parte sin tocar otras.
• La trazabilidad de responsabilidades se vuelve pobre.

BASELINE

PROBLEMA

esp32-motorized-door-controller

Etapa 2 · 2

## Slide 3

2. Arquitectura modular

Cada bloque recibe una responsabilidad clara y una frontera de cambio

Soporte transversal: logging + temporización/instrumentación para medir sin mezclar responsabilidades.

CDoorMotion no procesa JSON, no guarda NVS y no conoce pines: recibe configuración y callbacks; el .ino coordina el producto.

Materias: Programación Avanzada · Fundamentos de Programación · Sistemas Embebidos · Proyecto Final

motorized_door.ino | coordinador del producto

JSON · parámetros · NVS · requests

FSM · llegada · cruce · stall · timeout

DRV8833 · PWM · LEFT/RIGHT/STOP

AS5048A · SPI · ángulo/velocidad

CDoorConfig

CDoorMotion

CDoorMotor

CDoorSensor

REGLA DE DISEÑO

esp32-motorized-door-controller

Etapa 2 · 3

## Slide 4

3. FSM de posicionamiento explícita

La lógica deja de estar implícita en flags y pasa a una máquina de estados identificable

switch (state) { IDLE → espera | START → prepara movimiento | MOVING → controla cada período | SETTLING → espera y cierra }

La FSM encapsula el posicionamiento; el estado general del producto puede evolucionar por separado.

Materias: Programación Avanzada · Automatización · Proyecto Final

IDLE

START

MOVING

llegada / cruce
/ cancelación

SETTLING

start()

dirección

settle final → summary → IDLE

esp32-motorized-door-controller

Etapa 2 · 4

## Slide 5

4. Configuración sin recompilar

Comunicación y memoria pasan a formar parte de la arquitectura, no de la lógica de movimiento

Materias: Programación Avanzada · Fundamentos de Programación · Proyecto Final

• Comandos y consultas por Serial en formato JSON.
• Parámetros modificables en runtime.
• Requests pendientes separan comunicación de ejecución.

• Persistencia de posiciones y parámetros.
• Reinicio sin perder configuración.
• Base para una futura app de configuración.

El firmware deja de depender de constantes hardcodeadas.

La misma imagen puede probar configuraciones distintas sin recompilar, manteniendo una única baseline.

Resultado: experimentación más repetible y trazable.

HOST JSON

NVS

EFECTO

esp32-motorized-door-controller

Etapa 2 · 5

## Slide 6

5. Dos estrategias, una misma FSM

El modo de movimiento cambia la potencia aplicada; no cambia la lógica de posicionamiento

Principio de ingeniería: agregar una estrategia nueva sin destruir la referencia anterior.

Materias: Sistemas de Control · Programación Avanzada · Automatización · Proyecto Final

PWM fijo — baseline

• Usa pwm_move durante todo el recorrido.
• Conserva el comportamiento validado de la Etapa 1.
• Sirve como referencia A/B frente a cualquier mejora.

Approach no-PID

• Boost de arranque para vencer rozamiento.
• PWM base durante el recorrido.
• PWM reducido cerca del objetivo.

motion_mode=0

motion_mode=1

esp32-motorized-door-controller

Etapa 2 · 6

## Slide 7

6. El costo de la mejora empírica

Para intervenir sobre la física aparecen nuevas “perillas” que interactúan entre sí

Si cambia la mecánica, la carga, el rozamiento o el desgaste, estos parámetros deben volver a interpretarse y ajustarse.

Materias: Sistemas de Control · Automatización · Proyecto Final

Parámetro

Efecto físico

Riesgo si se ajusta mal

pwm_start

Vencer rozamiento/carga inicial

Exceso de energía e inercia

start_boost_ms

Duración del golpe inicial

Sobrepaso o arranque insuficiente

pwm_move

Potencia del recorrido principal

Compromiso velocidad/precisión

slow_zone_deg

Cuándo desacelerar

Llegada rápida vs. quedarse corto

pwm_slow

Potencia de aproximación

Stall cerca del target o sobrepaso

esp32-motorized-door-controller

Etapa 2 · 7

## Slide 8

7. Ensayo comparativo: ¿mejoró?

La respuesta es sí en confiabilidad de arranque, pero no de manera universal

Materias: Sistemas de Control · Automatización · Proyecto Final

Con carga, la mejora más clara fue la eliminación de stalls en esta tanda.

Lectura prudente: la muestra es comparativa, no una estadística definitiva.

ERROR PROMEDIO

PWM fijo

Approach

STALLS

2.51

2.34

0 g

0

Approach: 0

1.80

1.68

1.45

2 g

2

Approach: 0

1.41

8 g

1

Approach: 0

0 g

2 g

8 g

esp32-motorized-door-controller

Etapa 2 · 8

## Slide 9

8. Dos problemas distintos

La modularización mejora el software; no elimina la dependencia de la planta física

Conclusión: ya tenemos una base de software apta para experimentar; ahora falta dejar de adivinar la dinámica.

Materias: Programación Avanzada · Sistemas de Control · Proyecto Final

Problema resuelto

• Responsabilidades separadas.
• Baseline preservada.
• Configuración persistente y runtime.
• Nuevas estrategias pueden agregarse sin reescribir todo.

Problema todavía abierto

• Rozamiento e inercia siguen presentes.
• La carga modifica arranque y sobrepaso.
• El approach mejora casos, no una ley general.
• Más parámetros ≠ más conocimiento de la planta.

SOFTWARE

FÍSICA

esp32-motorized-door-controller

Etapa 2 · 9

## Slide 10

9. Decisión de continuidad

Cerrar la etapa de control empírico y convertir la planta en un objeto medible

APRENDIZAJE DE LA ETAPA

Una arquitectura escalable permite experimentar mejor; la siguiente decisión es medir la planta antes de sumar más parámetros.

Materias: Proyecto Final · Sistemas de Control · Programación Avanzada · Automatización

1

2

3

4

5

Baseline
modular

conservada

Approach
no-PID

probado

Límites
empíricos

identificados

Identificar
planta

siguiente paso

PD/PID

sobre evidencia

esp32-motorized-door-controller

Etapa 2 · 10

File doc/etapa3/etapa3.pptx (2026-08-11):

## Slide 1

Identificación de planta
y preparación PD/PID

Del Plotter Serial al primer modelo de la planta física

RESUMEN DE LA ETAPA
Se deja de “probar PWM” a ciegas y se mide cómo responde la planta real. Con PWM fijo se registran curvas travel vs tiempo, se estima velocidad útil, se identifica un modelo simple y se decide simular antes de implementar PD/PID en firmware.

Etapa 3

1

Plotter

2

PWM fijo

3

Curvas

4

Modelo

5

Simular

Materias: Sistemas de Control · Programación Avanzada · Automatización · Proyecto Final

esp32-motorized-door-controller

Etapa 3 · 1

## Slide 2

Punto de partida

La etapa anterior dejó una baseline, no una solución de control final

Lo que ya sabemos
• La plataforma física se mueve.
• El sensor lee a tiempo.
• El firmware monolítico permitió medir.
• El PWM fijo no alcanza para todas las condiciones.

Materias: Sistemas de Control · Proyecto Final · Programación Avanzada

Nueva pregunta de I+D
¿Cómo responde realmente la planta cuando aplicamos una entrada conocida?
La respuesta no se supone: se mide.

esp32-motorized-door-controller

Etapa 3 · 2

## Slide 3

Instrumentar antes de controlar

Usar el Plotter como herramienta de observación de la planta

Criterio de ensayo
• Usar motion_mode=0.
• Mantener PWM fijo en cada corrida.
• Registrar travel y target.
• Evitar confusiones por wrap 0/360.
• No modificar motor, sensor ni lógica ya validada.

Materias: Programación Avanzada · Sistemas de Control · Instrumentación

Configuración
PLANT_PLOT_PERIOD_MS = 50 ms
Cada muestra representa aproximadamente 0,05 s.
PWM ensayados: 70, 75 y 80.

esp32-motorized-door-controller

Etapa 3 · 3

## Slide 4

Curvas travel vs tiempo

El Plotter transforma movimiento en datos observables

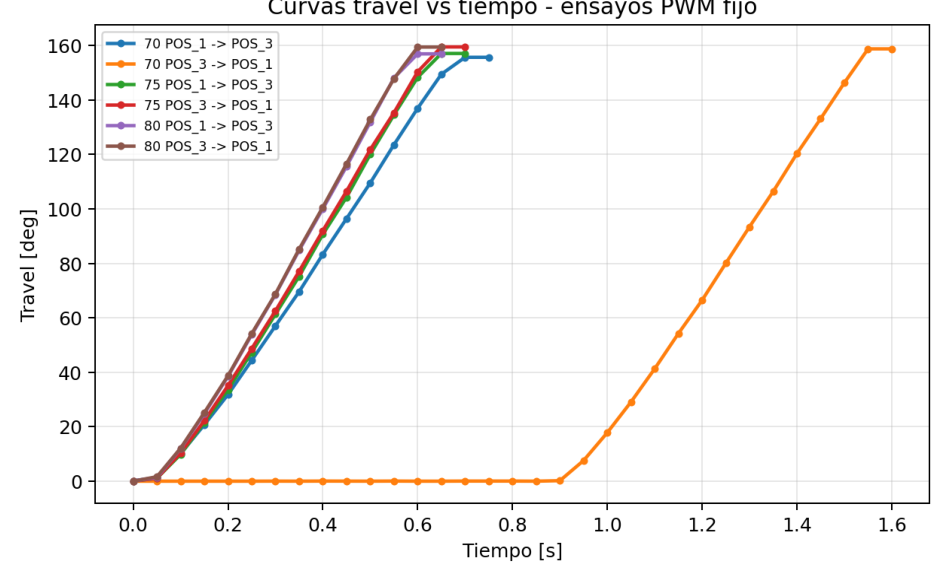
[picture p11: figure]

Materias: Sistemas de Control · Análisis de datos · Programación Avanzada

Lectura de la gráfica
• La mayoría de las curvas suben casi linealmente una vez que el motor despega.
• PWM mayor produce pendiente mayor.
• El caso PWM 70 en un sentido muestra retardo de arranque marcado.
La curva ya separa tres momentos: arranque, régimen y llegada.

esp32-motorized-door-controller

Etapa 3 · 4

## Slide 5

Comparación por sentido

La planta se parece, pero no siempre arranca igual

En régimen, ambos sentidos muestran velocidades parecidas. La diferencia importante aparece en el arranque: no basta con mirar la pendiente final.

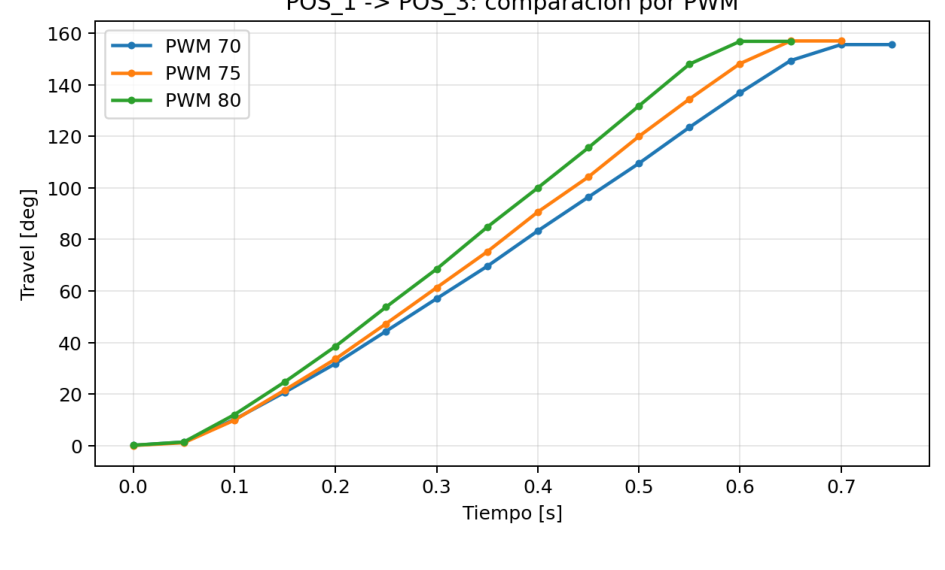
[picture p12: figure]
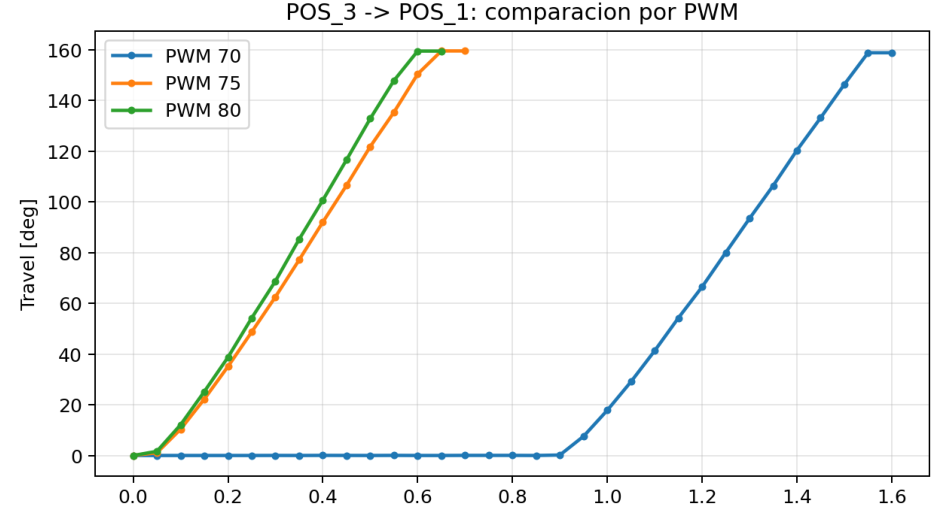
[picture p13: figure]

Materias: Sistemas de Control · Automatización · Análisis de datos

esp32-motorized-door-controller

Etapa 3 · 5

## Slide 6

Arranque marginal

PWM 70 no era lento: a veces tardaba en despegar

Hallazgo clave
Con PWM 70, POS_3 → POS_1 tuvo un retardo cercano a 0,95 s antes de que el travel empezara a crecer.
Una vez que el motor se movió, la velocidad útil fue similar.
Interpretación: fricción estática, zona muerta de arranque o condición mecánica puntual.

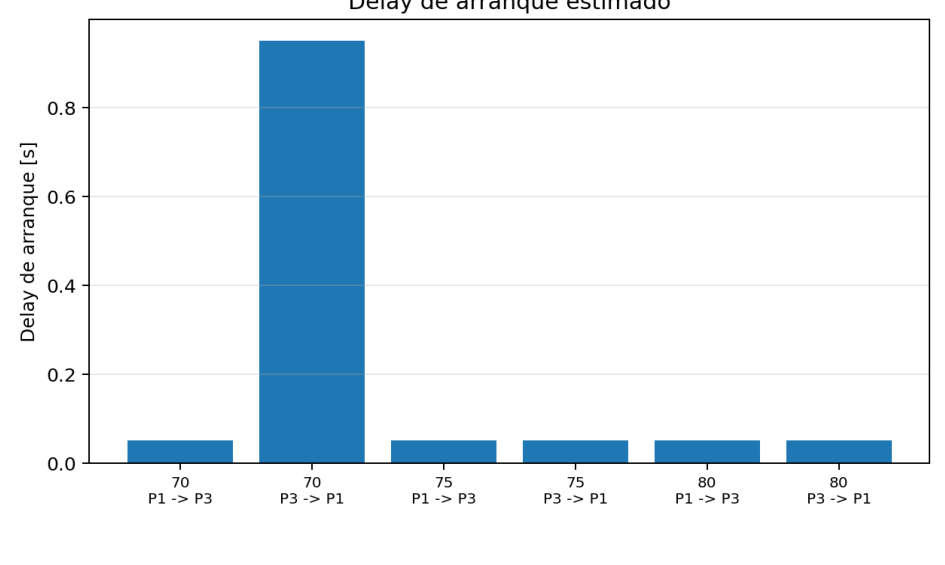
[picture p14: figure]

Materias: Sistemas de Control · Automatización · Mecánica aplicada

esp32-motorized-door-controller

Etapa 3 · 6

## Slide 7

De la curva a la velocidad útil

La pendiente central evita contaminar el cálculo

Método
La velocidad útil se estima con regresión lineal en la zona central de la curva. Así se evita mezclar el cálculo con retardo de arranque, inercia de llegada o muestras finales repetidas.

Pendiente de travel vs tiempo = velocidad útil

Arranque
no usar

Zona útil
10% a 85%

Llegada
evitar

Materias: Análisis de datos · Sistemas de Control · Programación Avanzada

esp32-motorized-door-controller

Etapa 3 · 7

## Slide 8

Datos resumidos

PWM mayor produce mayor velocidad útil

PWM

Vel. medida

Vel. modelo

70

258,4 °/s

258,7 °/s

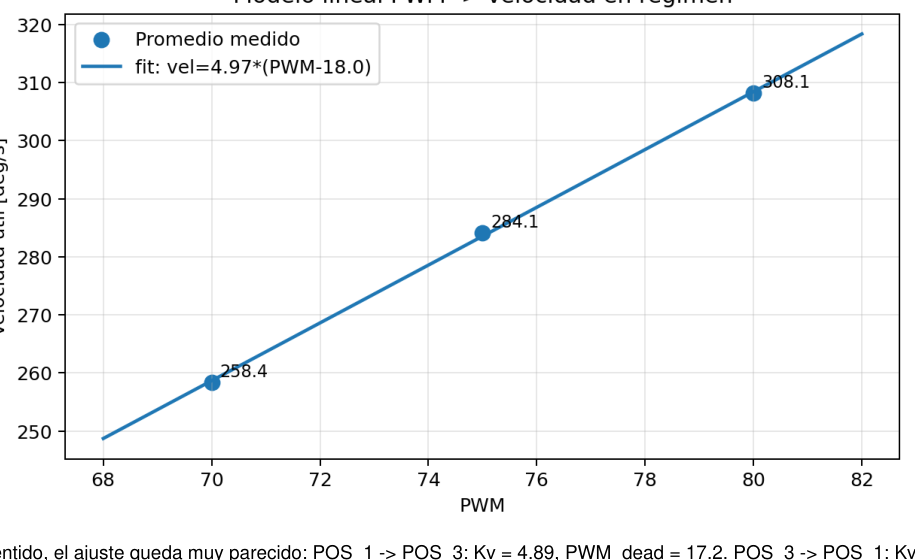
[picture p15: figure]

75

284,1 °/s

283,5 °/s

80

308,1 °/s

308,4 °/s

El ajuste medido y el modelo prácticamente coinciden en el rango usado. Esto habilita una simulación inicial simple.

Materias: Sistemas de Control · Análisis de datos

esp32-motorized-door-controller

Etapa 3 · 8

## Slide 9

Modelo de planta identificado

Una aproximación simple para empezar a simular

Modelo propuesto
velocidad_deg_s = Kv · (PWM − PWM_dead)
travel(t) = ∫ velocidad_deg_s dt

Ajuste promedio
velocidad_deg_s ≈ 4,97 · (PWM − 18)

Interpretación
• PWM_dead ≈ zona muerta promedio.
• Kv ≈ ganancia de velocidad.
• El modelo describe bien el régimen, pero no reemplaza la validación física.
• Conviene separar arranque y movimiento en régimen.

Materias: Sistemas de Control · Modelado · Proyecto Final

esp32-motorized-door-controller

Etapa 3 · 9

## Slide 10

Implicancias para PD/PID

No implementar todavía: simular primero

Estrategia conservadora: comenzar con PD, Ki=0, y sumar integral pequeña solo si luego queda justificado por las pruebas.

P · Proporcional
Error grande → más esfuerzo.
Cerca del objetivo → menos salida.

D · Derivativo
Amortigua por velocidad.
Ayuda a reducir sobrepaso al acercarse.

I · Integral
Corrige error persistente.
Debe tener límites y anti-windup.

Materias: Sistemas de Control · Programación Avanzada · Proyecto Final

esp32-motorized-door-controller

Etapa 3 · 10

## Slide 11

Plan de simulación

Probar control sobre el modelo antes de tocar la baseline

El firmware validado no debe tocarse hasta tener curvas simuladas razonables y constantes iniciales conservadoras. La futura implementación puede entrar como motion_mode=2, conservando motion_mode=0 como baseline.

1

2

3

4

5

6

Target
157–160°

dt
0,005–0,010 s

Modelo
PWM → velocidad

Saturación
PWM máximo

PD primero
Ki=0

Validar
hardware

Materias: Sistemas de Control · Simulación · Programación Avanzada · Proyecto Final

esp32-motorized-door-controller

Etapa 3 · 11

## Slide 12

Cierre de la etapa

La planta ya tiene una primera descripción medible

La etapa demuestra que el problema de control ya puede tratarse con datos: no se trata de adivinar parámetros, sino de medir la planta, modelar lo dominante y preparar una implementación conservadora.

Plotter
Datos reales

Curvas
Travel vs tiempo

Velocidad
Pendiente útil

Modelo
PWM → velocidad

Simulación
Siguiente decisión

Materias: Integración de competencias · Sistemas de Control · Proyecto Final

esp32-motorized-door-controller

Etapa 3 · 12

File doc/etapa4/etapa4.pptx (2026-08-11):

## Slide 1

Etapa 4

Simulación, PID en hardware
y validación con carga

De un modelo identificado a un controlador aplicado sobre la maqueta real

Modelo

Simulación

Hardware

Carga

Cierre

1

2

La simulación no reemplazó al ensayo: permitió partir de un set razonable. En hardware se ajustó la zona no lineal real —fricción, arranque y carga— sin romper la arquitectura ni abandonar la baseline.

Idea fuerte: se sintonizó fácil porque antes hicimos bien el trabajo.

RESUMEN DE LA ETAPA

3

4

5

Materias: Sistemas de Control · Programación Avanzada · Automatización · Proyecto Final

esp32-motorized-door-controller

Etapa 4 · 1

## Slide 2

1. Punto de partida: simular sobre una planta medida

La etapa anterior entregó un modelo simple y suficiente para probar control antes de tocar el firmware

No se implementó PID a ciegas.

Se midió la planta con PWM fijo.
Se propuso un modelo PWM → velocidad → travel.
Se simuló en Python para elegir constantes iniciales conservadoras.
El firmware validado se mantuvo como baseline.

Simular no es adivinar: es probar una hipótesis contra un modelo medido.

CRITERIO I+D

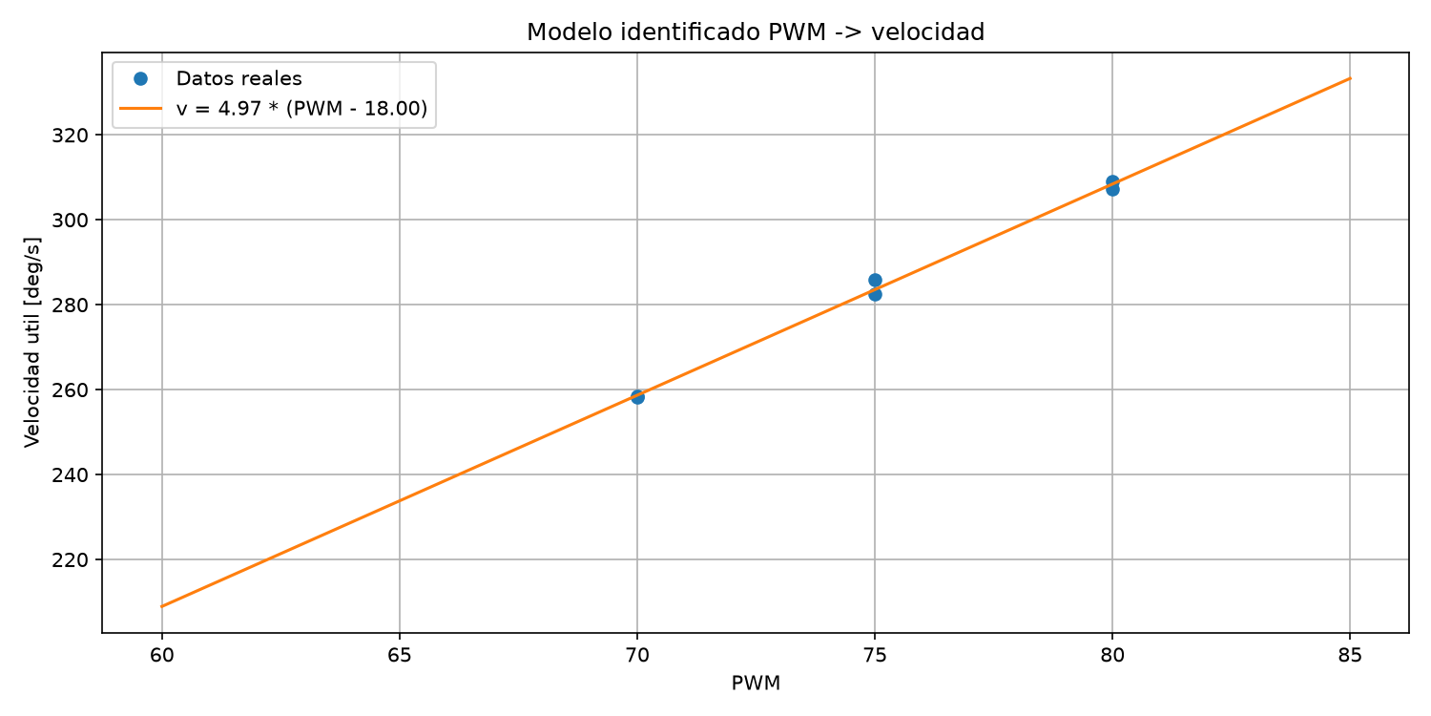
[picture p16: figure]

Materias: Sistemas de Control · Análisis de datos · Proyecto Final

esp32-motorized-door-controller

Etapa 4 · 2

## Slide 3

2. Qué mostró la simulación

Trayectoria, componentes del PID y PWM aplicado antes de llevarlo al hardware

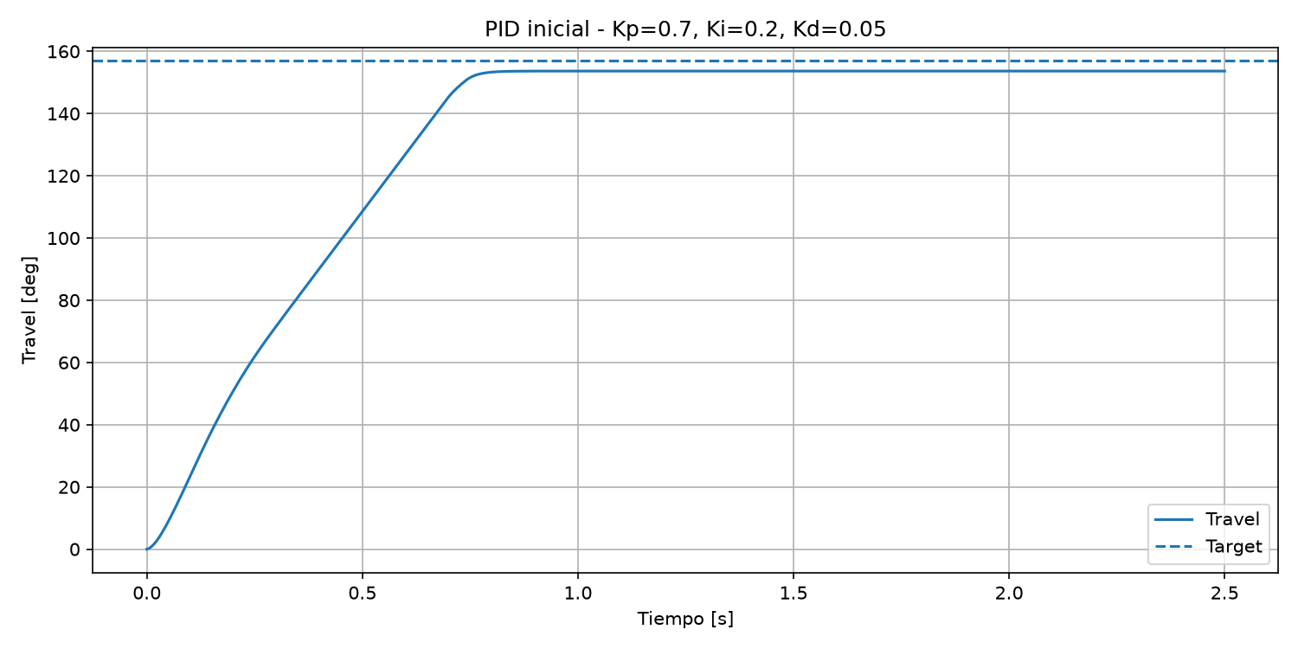
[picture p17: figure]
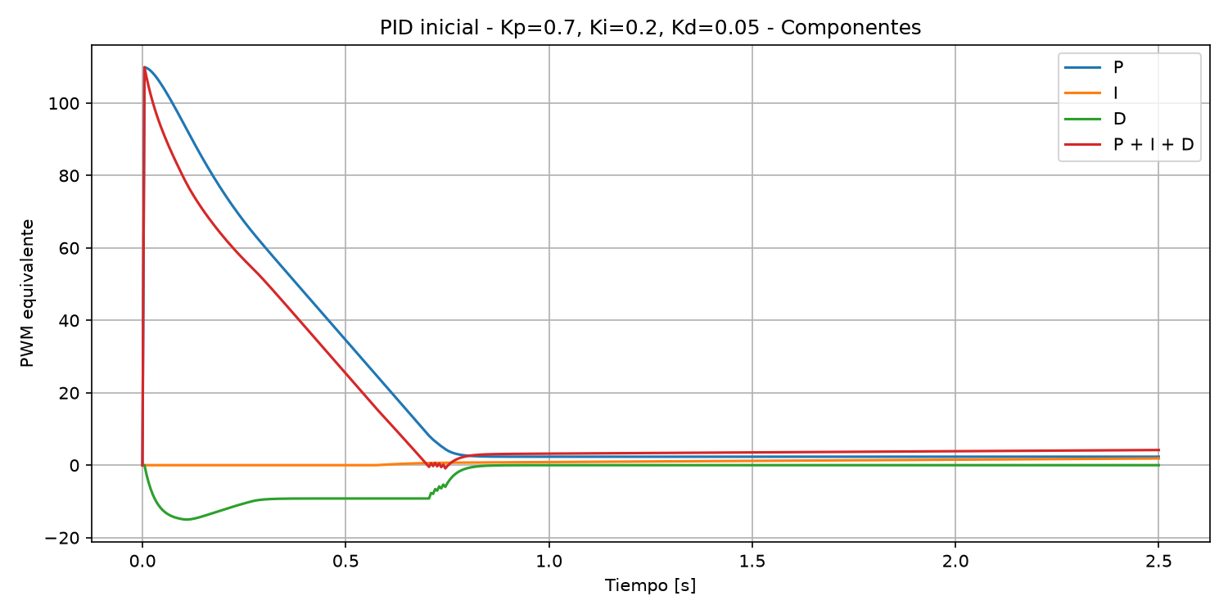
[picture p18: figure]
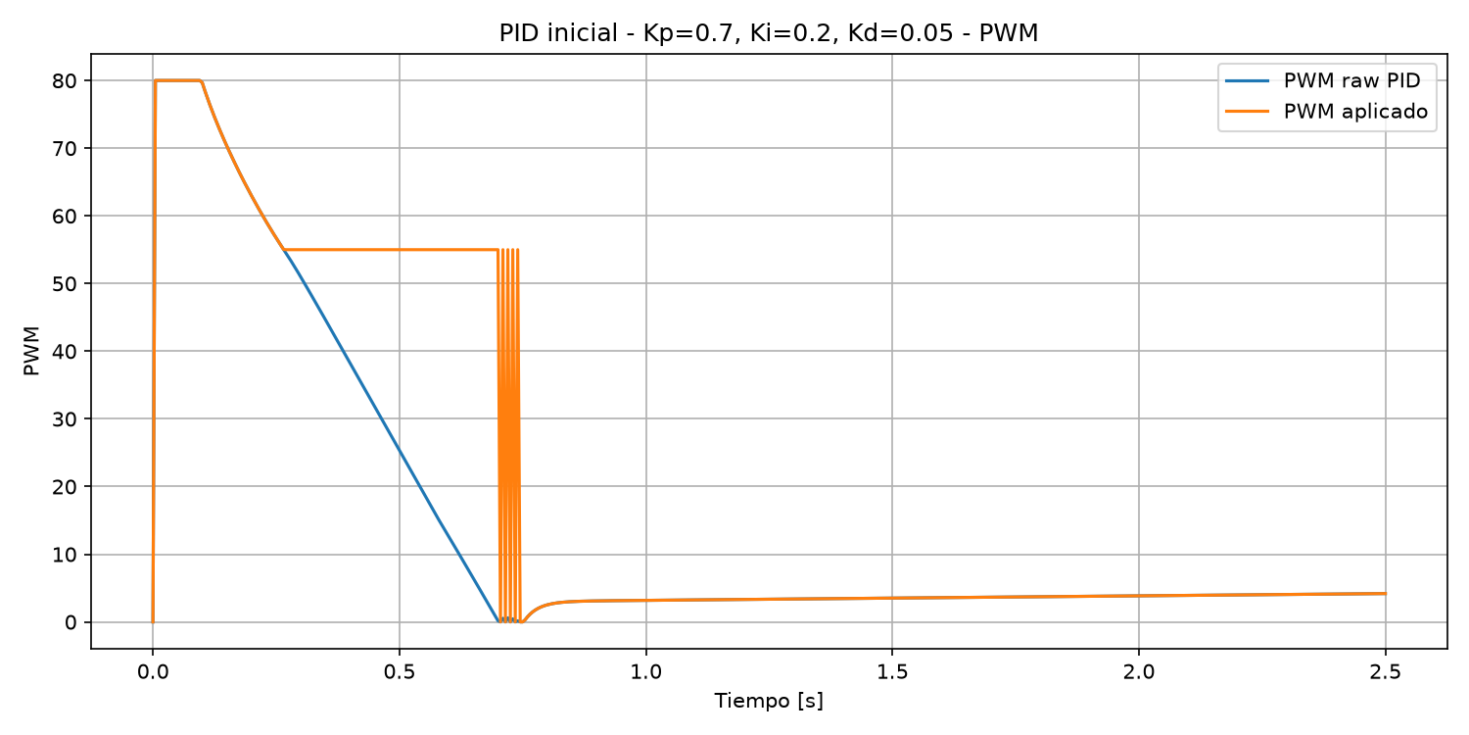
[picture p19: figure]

La simulación permitió mirar tres cosas que en el prototipo real no se ven a simple vista: la trayectoria, la contribución P/I/D y la diferencia entre PWM calculado y PWM aplicado.

Materias: Sistemas de Control · Programación/Python · Análisis de datos

esp32-motorized-door-controller

Etapa 4 · 3

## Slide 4

3. La frase clave de la etapa

La facilidad de ajuste no fue casualidad: fue consecuencia del trabajo previo

“Se sintonizó fácil porque antes hicimos bien el trabajo:
identificar planta, simular y conservar baseline.”

1
Medir
la planta

2
Simular
barato

3
Implementar
incremental

4
Ajustar
lo real

La experiencia técnica no reemplaza el método: ayuda a elegir qué medir, qué conservar y qué tocar.

Materias: Proyecto Final · Sistemas de Control · Metodología de I+D

esp32-motorized-door-controller

Etapa 4 · 4

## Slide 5

4. De la simulación al hardware

Qué se mantuvo y qué hubo que recalibrar cuando apareció la física real

Parámetro

Kp

Simulación

0.70

Hardware v4.1c

0.70

Lectura

Se mantuvo: buena escala proporcional.

Ki

0.00

0.05

Se agregó para corregir error fino por fricción.

Kd

0.05

0.05

Se mantuvo: aporta amortiguamiento.

PWM máx.

PWM mín. efectivo

80

55

80

75

Límite seguro conservado.

El hardware exigió más para vencer arranque/fricción.

Zona mín. efectiva

6°

2°

Se bajó para no empujar de más cerca del target.

Integral activa

Límite integral

35°

120

20°

120

Integral acotada a zona de llegada.

Con Ki=0.05 aporta solo ±6 PWM.

Materias: Sistemas de Control · Electrónica · Automatización · Proyecto Final

esp32-motorized-door-controller

Conclusión: la simulación acertó la dinámica gruesa; el hardware ajustó la no linealidad.

Etapa 4 · 5

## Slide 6

5. Qué quedó implementado en v4.1c

PID durante MOVING; todavía sin HOLDING activo

La versión cierra el movimiento. No intenta mantener posición activamente después de llegar.

FLUJO

motion_mode = 2
Kp / Ki / Kd = 0.70 / 0.05 / 0.05
PWM máximo = 80
PWM mínimo efectivo = 75 si error > 2°
Integral activa hasta 20° con acumulador limitado
Aporte máximo de I: ±6 PWM equivalente

SET BASE

START

MOVING
PID

SETTLING

IDLE

Materias: Programación Avanzada · Sistemas de Control · Automatización

esp32-motorized-door-controller

Etapa 4 · 6

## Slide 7

6. La no linealidad real: PWM matemático vs movimiento físico

El PID puede pedir poco, pero el motor real necesita vencer fricción y zona muerta

El controlador calcula una salida continua.
El motor ejecuta una acción física.

Por debajo de cierto PWM, el motor puede no moverse.
El PWM mínimo efectivo no es un capricho: representa fricción y arranque.
Cerca del target, forzar demasiado PWM puede crear sobrepaso.
Por eso se acota dónde y cuándo aplicar el mínimo efectivo.

APRENDIZAJE

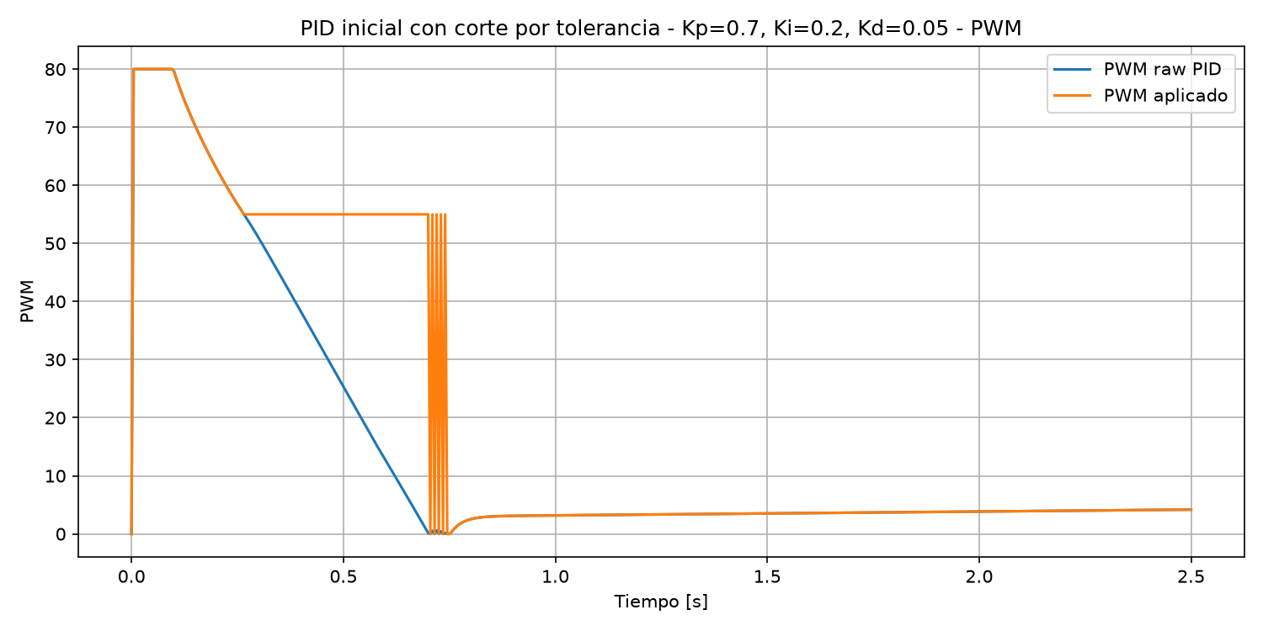
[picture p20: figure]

Materias: Sistemas de Control · Electrónica de potencia · Automatización

esp32-motorized-door-controller

Etapa 4 · 7

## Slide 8

7. Resultados con cargas prácticas

El PID de movimiento absorbió variaciones razonables sin cambiar la arquitectura

Condición

Movimientos

Stall

Error típico

Lectura

Sin carga

POS_3, POS_1, POS_2, POS_3

0/3

-0.42° a -1.28°

Base OK

Carga 8 g

4 movimientos

0/3

-1.83° a +1.03°

OK

Carga 14 g

4 movimientos

0/3

-1.59° a +0.99°

OK

Carga 20 g

5 movimientos

2 fallas POS_3

borde

Fuera de rango

Lectura: 8 g y 14 g validan variaciones prácticas; 20 g documenta el borde, no una especificación de producto.

Materias: Sistemas de Control · Ensayo experimental · Proyecto Final

esp32-motorized-door-controller

Etapa 4 · 8

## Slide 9

8. Prueba extrema: 20 g no es producción

El montaje agrega más variables que una carga limpia

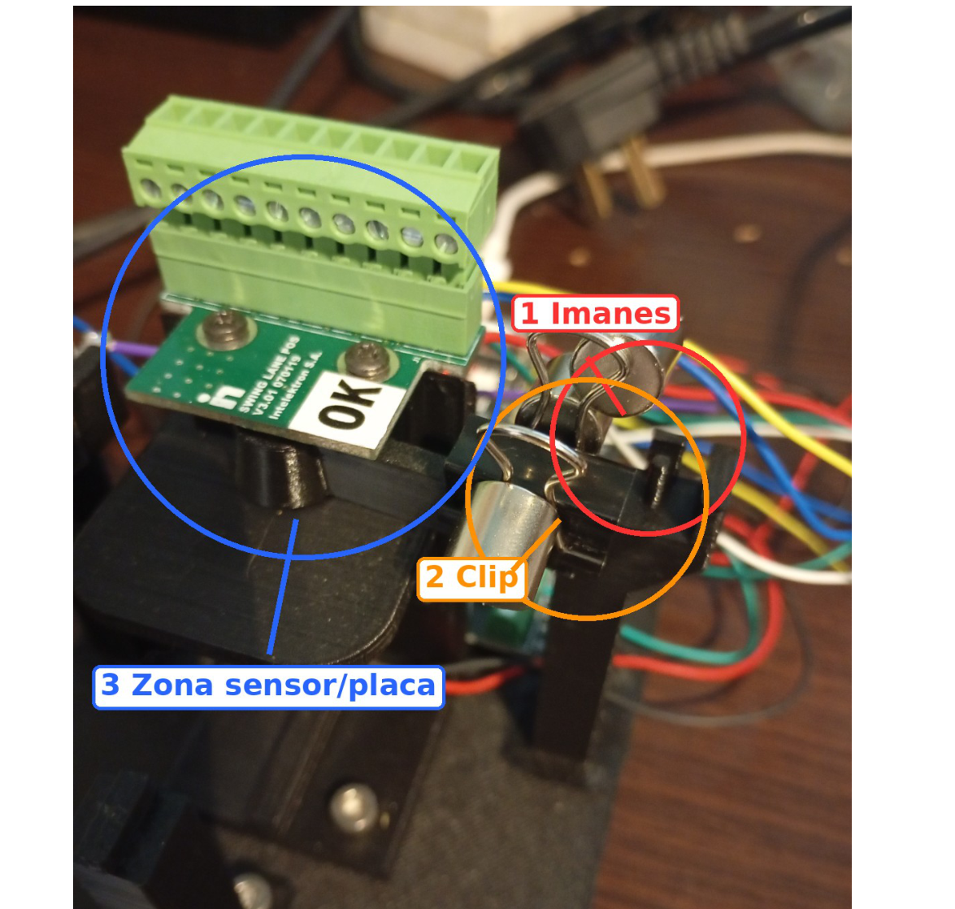
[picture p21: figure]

Un N20 no es un eje industrial.

Estos motorreductores suelen mover ruedas o engranajes pequeños.
No conviene aplicarles cargas axiales, laterales o palancas sobre el eje.
El clip + imanes introdujo torque variable, rozamiento posible y campo cerca del AS5048A.
El ensayo sirve como estrés intencional, no como diseño mecánico recomendado.

Conclusión: cuando la mecánica queda fuera de rango, el controlador no debe ser culpado ni usado para tapar un problema de diseño.

ADVERTENCIA MECÁNICA

Materias: Automatización · Mecánica/electromecánica · Sensores · Proyecto Final

esp32-motorized-door-controller

Etapa 4 · 9

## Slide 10

9. Lectura para un producto real

En una pasarela real, la planta incluye muchas más piezas y tolerancias

Motor

Embrague

Eje

Reductora

Puerta

Rodamientos

Topes

Montaje

La planta real no es “el motor”: es el conjunto completo. Cada tolerancia de montaje cambia la respuesta.

En producción se mide una familia de plantas. Una vez conocida la media y la dispersión, la sintonización suele ser homogénea y las unidades particulares se corrigen por calibración.

Materias: Proyecto Final · Sistemas de Control · Automatización · Manufactura

esp32-motorized-door-controller

Etapa 4 · 10

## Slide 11

10. ¿Qué se puede mostrar en video?

La maqueta quizá no muestre grandes variaciones de carga, pero sí muestra el método

Que el sistema llega repetidamente.
Que los parámetros vienen de simulación, no de tanteo ciego.
Que el hardware obligó a recalibrar fricción y PWM mínimo.
Que 8 g y 14 g no rompieron la llegada.

SE PUEDE MOSTRAR

Un PID “mágico” visible a simple vista.
Una validación de seguridad industrial.
Una sintonización final de una puerta real.
Una prueba de carga limpia en 20 g.

NO VENDER COMO

Materias: Comunicación técnica · Proyecto Final · Sistemas de Control

esp32-motorized-door-controller

Mensaje para el video: el valor no está solo en que se mueva; está en cómo se llegó a un set defendible.

Etapa 4 · 11

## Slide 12

11. Cierre de la Etapa 4

PID de movimiento aceptado; quedan decisiones de producto

PID moving
v4.1c

Aceptado

✓

Carga
práctica

8 g / 14 g OK

✓

20 g

Fuera de rango

✓

HOLDING

Pendiente

✓

Producto

Próximo branch

✓

Recomendación técnica: cerrar v4.1c como control PID de movimiento aceptado y pasar a la etapa de HOLDING / control de dispositivo.

La simulación dio una base cercana; el banco real corrigió lo que el modelo simple no podía conocer.

Materias: Integración de competencias · Proyecto Final

esp32-motorized-door-controller

Etapa 4 · 12

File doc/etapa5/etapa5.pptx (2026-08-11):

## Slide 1

Etapa 5

Motor nuevo, LED y
revisión del controlador

Un caso real de I+D: observar un síntoma, aislar causas y revisar una decisión previa

Síntoma doble

Descartes

Plotter

Causa

Decisión

1

2

Después de reemplazar el N20, aparecieron dos síntomas simultáneos: un tironeo físico cerca de la llegada y un cambio visual errático en la tira LED. El análisis mostró que no eran fallas independientes: ambos seguían una inversión breve de sentido generada por el control.

Resultado: Kp se conserva, Ki y Kd se anulan, y el LED queda como evidencia visual del diagnóstico.

RESUMEN DE LA ETAPA

3

4

5

Materias: Sistemas de Control · Programación Avanzada · Electrónica · Proyecto Final

esp32-motorized-door-controller

Etapa 5 · 1

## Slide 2

1. Contexto: la planta cambió y apareció un síntoma doble

El motor nuevo no fallaba: cambió la respuesta física que veía el controlador

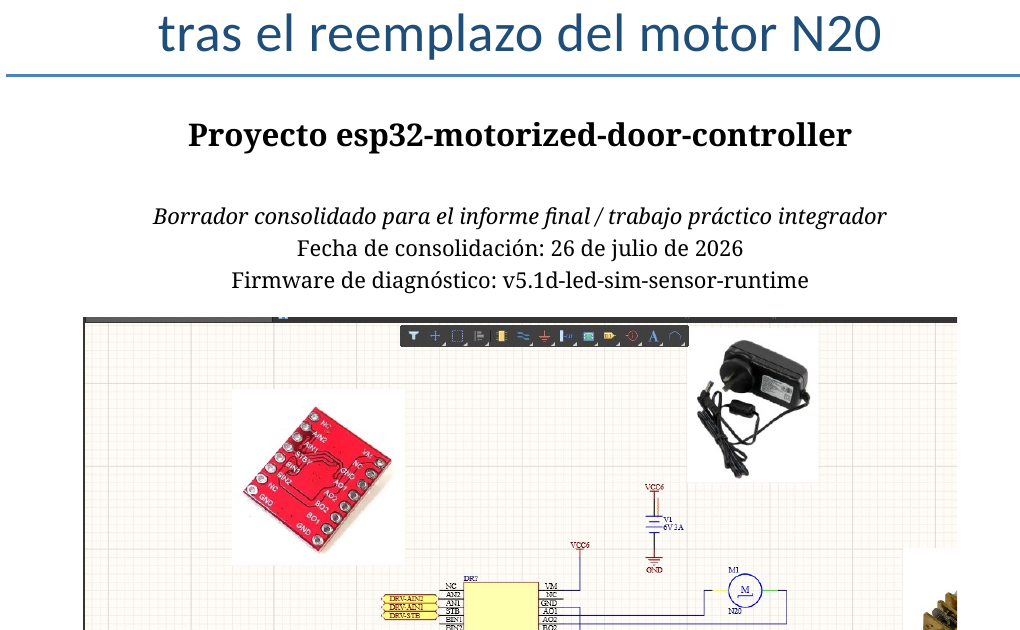
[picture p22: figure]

Tironeo físico

La puerta llegaba.
No aparecía stall.
Pero cerca del target se veía una patada o contramarcha.

MOTOR

Cambio visual

La animación parecía errática.
El salto visual coincidía con el tironeo.
Al inicio no sabíamos si era causa o síntoma.

LED

Punto de partida: el LED se observa desde el comienzo junto con el tironeo; todavía no se interpreta como causa.

Materias: Automatización · Sistemas de Control · Diagnóstico experimental

esp32-motorized-door-controller

Etapa 5 · 2

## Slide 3

2. Primeras hipótesis: no asumir la causa

El cambio de motor ocurrió mientras se integraba la tira LED: no había que culpar al primer síntoma visible

Contexto real: motor nuevo + LED en desarrollo + firmware no estabilizado ⇒ había que aislar antes de decidir.

VM, GND, capacitor, caída de tensión

La WS2812B se estaba agregando al firmware. Podía interferir, o podía estar mostrando un estado real.

Reductora, rozamiento, montaje o sensibilidad mecánica

Salida PD, signo de dirección y PWM mínimo efectivo

Alimentación

LED / integración

Motor nuevo

Control

Templanza de I+D: cuando el firmware todavía está en integración, no se corrige “a ojo”; se separan fenómenos y se vuelve a una base conocida.

Materias: Proyecto Final · Electrónica · Programación Avanzada

esp32-motorized-door-controller

Etapa 5 · 3

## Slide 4

3. Descartes: LED y alimentación no explicaban el tironeo

El LED seguía siendo una pista, pero no era la causa primaria del movimiento físico

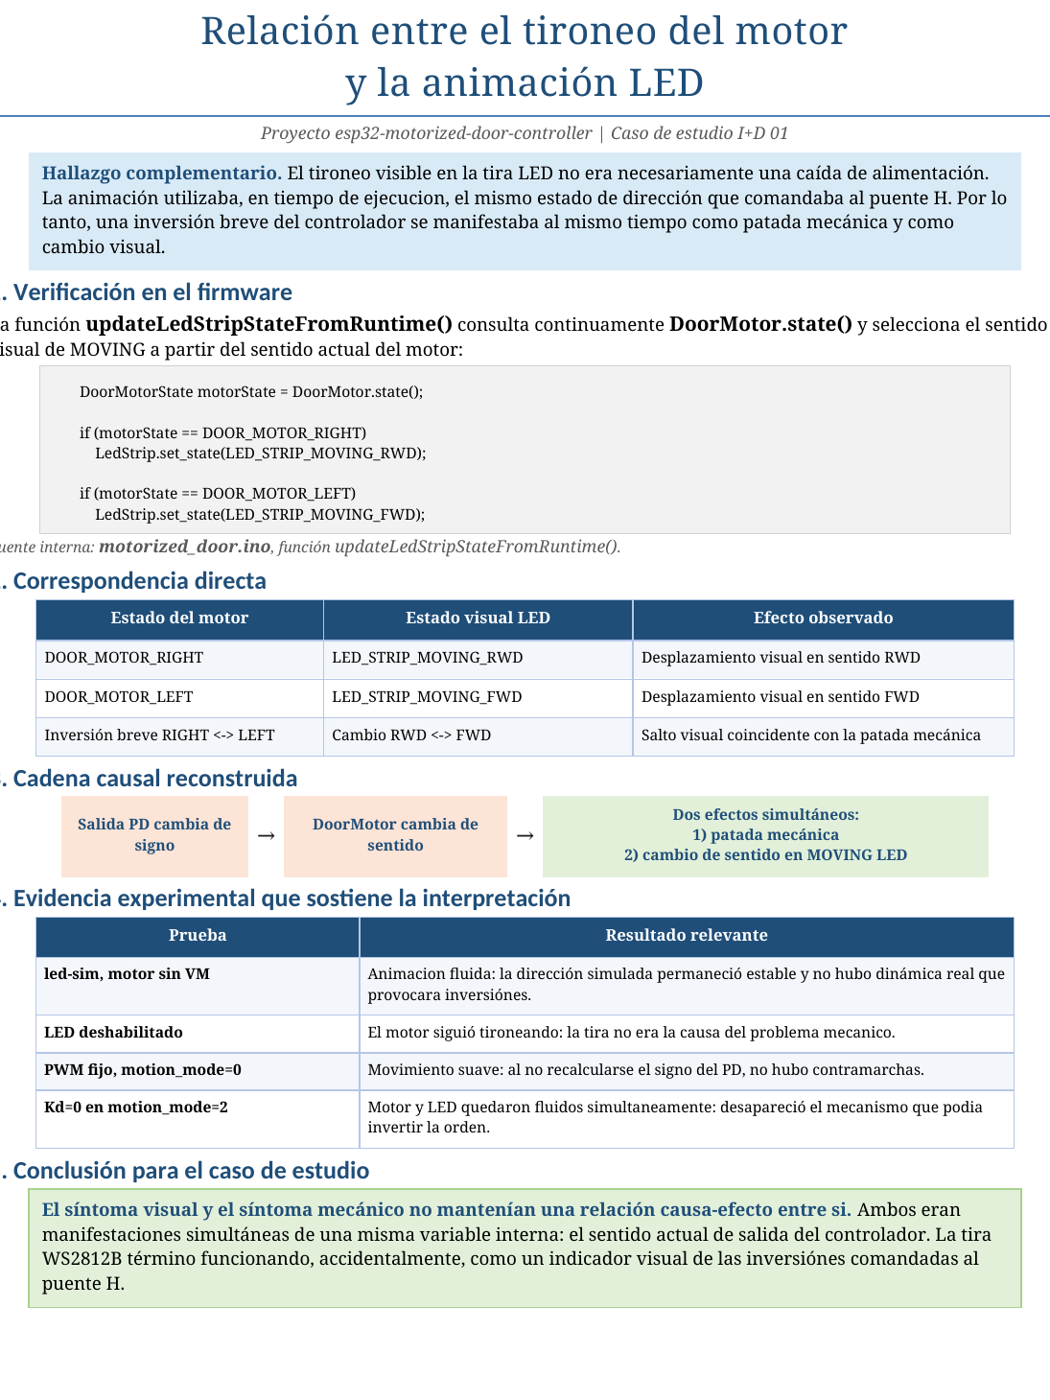
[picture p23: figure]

Con LED apagado, el motor siguió tironeando.
Con led-sim y motor sin VM, la animación era fluida.
La tira no generaba la falla mecánica.

PRUEBAS LED

Se probó desacople con capacitor.
El síntoma no desapareció.
Queda útil como mejora eléctrica, pero no explica la causa.

ALIMENTACIÓN

Conclusión intermedia: el LED seguía mostrando algo real, pero el origen debía buscarse en la orden de movimiento.

Materias: Electrónica I/II/III · Diagnóstico experimental

esp32-motorized-door-controller

Etapa 5 · 4

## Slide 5

4. PWM fijo: la planta podía moverse suave

Al sacar el cálculo PD, el motor nuevo y la mecánica no mostraron tironeo

La falla no estaba en “el motor nuevo” aislado.

motion_mode=0 con PWM fijo resultó visualmente suave.
Llegó a POS_1, POS_2 y POS_3 sin tironeo.
Se debilitó la hipótesis de falla intrínseca del motor, reductor, driver o cableado.
El problema apareció al sumar el cálculo PD.

LECTURA

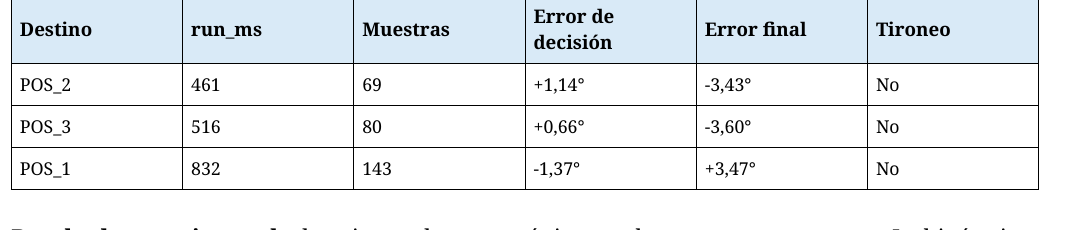
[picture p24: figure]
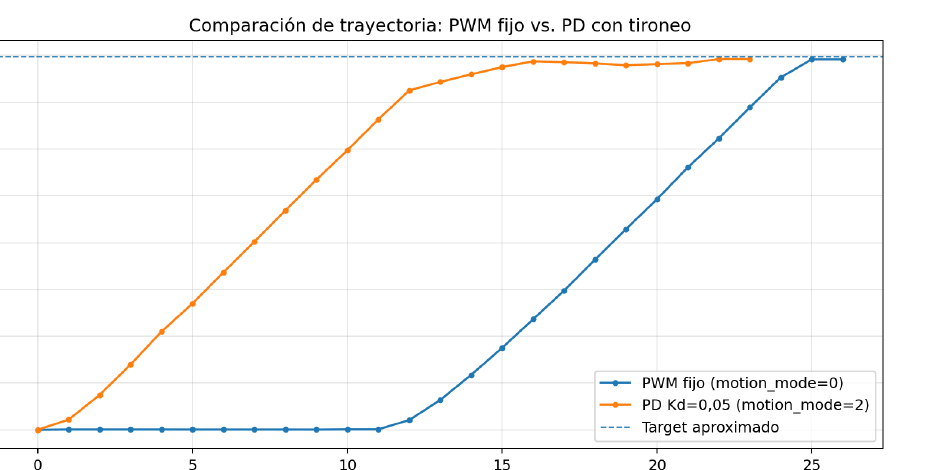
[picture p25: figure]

Materias: Sistemas de Control · Automatización · Ensayo experimental

esp32-motorized-door-controller

Etapa 5 · 5

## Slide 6

5. El resumen final no alcanzaba

El AUTO SUMMARY decía “llegó”; no guardaba la historia de cada ciclo de control

Útil para validar la llegada.

reason = posicion_alcanzada
stall_count = 0/3
tiempo total y error final
último estado observado

SUMMARY FINAL

La secuencia interna.

PWM de cada ciclo
dirección comandada
posición cada 5 ms
reversiones breves cerca de la llegada

FALTABA VER

Conclusión didáctica: una métrica agregada puede ocultar un problema transitorio.

Materias: Instrumentación · Programación · Sistemas de Control

esp32-motorized-door-controller

Etapa 5 · 6

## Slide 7

6. El Plotter reveló la inversión de sentido

Con Kd=0,05 apareció un retroceso acumulado de 1,63° cerca de la llegada

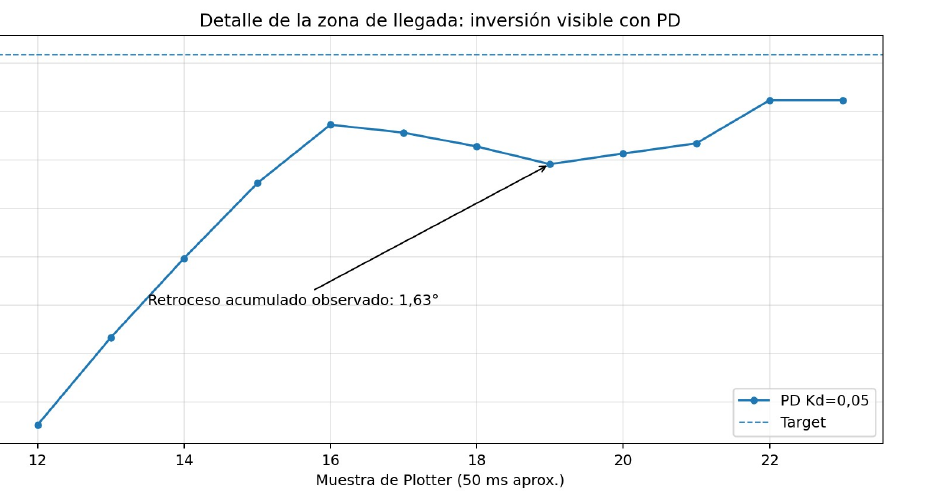
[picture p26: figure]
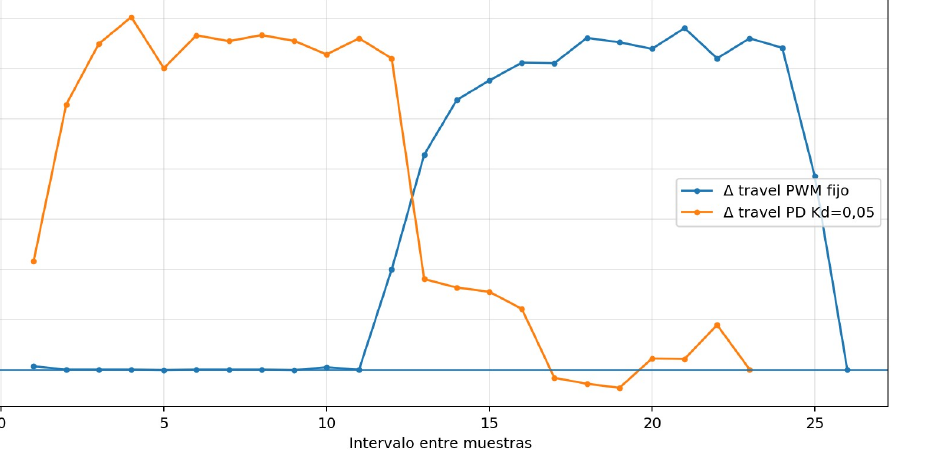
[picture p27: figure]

La evidencia dejó de ser “se siente raro” y pasó a ser una medición: tres incrementos negativos consecutivos en la zona de llegada.

Materias: Análisis de datos · Sistemas de Control · Instrumentación

esp32-motorized-door-controller

Etapa 5 · 7

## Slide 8

7. Relectura del LED: no era causa, era evidencia

Después de identificar la inversión, el LED permitió confirmar que seguía la orden de sentido

if motor == RIGHT:
LED_RWD
if motor == LEFT:
LED_FWD

Kd=0,05
puede invertir
el signo de u

DoorMotor
cambia
de sentido

Puente H
manda
contramarcha

LED usa
el mismo estado
MOVING_FWD/RWD

CÓDIGO

Conclusión: el salto visual y la patada mecánica no eran causa y efecto. Ambos expresaban la misma inversión breve de sentido comandada al puente H.

Esta explicación solo apareció después de observar, descartar, instrumentar y medir.

Materias: Programación Avanzada · Electrónica · Sistemas de Control

esp32-motorized-door-controller

Etapa 5 · 8

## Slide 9

8. Interpretación: una salida pequeña se volvió contramarcha real

La combinación D + signo de salida + PWM mínimo efectivo amplificó un cambio breve

u = P + D

dirección = signo(u)
PWM = abs(u)
si 0 < PWM < 70
y error > 2°:
PWM = 70

Una corrección matemática pequeña de signo contrario puede mandar una contramarcha física a PWM 70.

MECANISMO

Cerca de la llegada, P se achica porque el error baja.
D puede tomar peso relativo si la velocidad todavía es alta.
Si D supera momentáneamente a P, cambia el signo de la salida.
El nuevo motor hizo visible una condición que el anterior no excitaba tanto.

POR QUÉ APARECIÓ AHÍ

Materias: Sistemas de Control · Firmware embebido · Electrónica de potencia

esp32-motorized-door-controller

Etapa 5 · 9

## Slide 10

9. Ensayo controlado: cambiar solo Kd

Se mantiene el modo de control y se modifica únicamente Kd de 0,05 a 0

motion_mode = 2
Kp = 0,7
Ki = 0
Kd: 0,05 → 0

CONDICIÓN

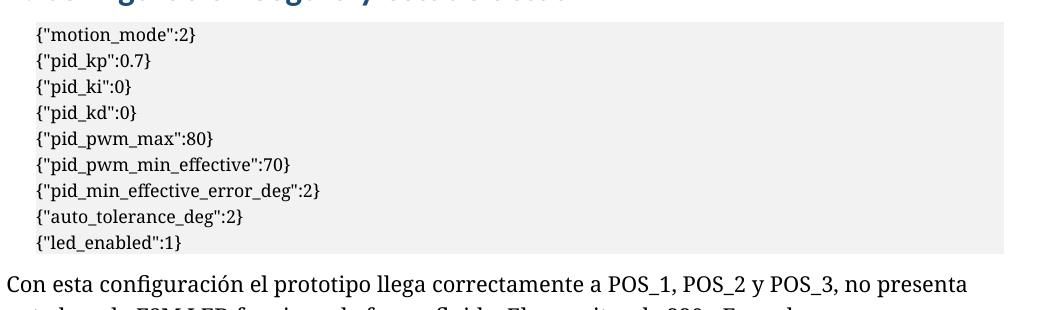
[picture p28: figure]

El tironeo desapareció.
Las llegadas fueron sanas.
El LED dejó de saltar porque ya no había contramarcha que seguir.
Se conserva evidencia para una futura corrección estructural del PD.

RESULTADO

Set seguro actual:
Kp=0,7 · Ki=0 · Kd=0

Materias: Sistemas de Control · Programación Avanzada · Proyecto Final

esp32-motorized-door-controller

Etapa 5 · 10

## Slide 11

10. Decisión de I+D

No todo hallazgo exige resolver el problema general si el producto necesita avanzar con una solución segura

No tocar
todo

Cambiar una sola variable permitió atribuir causa.

No forzar
PD ahora

La solución estructural queda diferida con evidencia.

Conservar
baseline
+ modos

motion_mode permite comparar y volver a una configuración segura.

Avanzar
producto

Seguir con LED rojo, FSM superior y app sobre una arquitectura escalable.

1

2

3

4

La decisión no fue “el PID falló”: fue conservar una arquitectura configurable, simplificar el controlador y avanzar con una solución segura.

Materias: Proyecto Final · Gestión de I+D · Sistemas de Control

esp32-motorized-door-controller

Etapa 5 · 11

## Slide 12

11. Caso integrador de disciplinas

El diagnóstico conecta control, firmware, electrónica, sensores, mecánica y método experimental

Observar un síntoma físico y no quedarse con el resultado final del firmware.
Formular hipótesis y diseñar pruebas que las separen.
Usar instrumentación para ver lo que el ojo no alcanza.
Aceptar que una conclusión previa puede revisarse con evidencia nueva.
Documentar una solución posible sin venderla como única o definitiva.

COMPETENCIAS

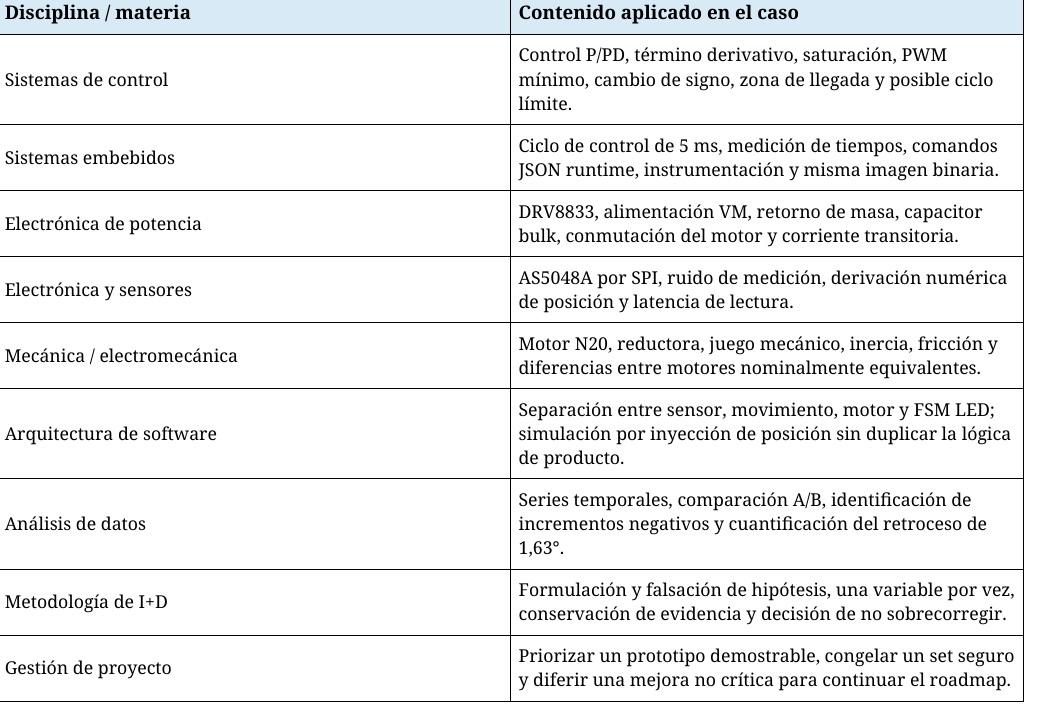
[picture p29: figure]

Materias: Integración de competencias · Proyecto Final

esp32-motorized-door-controller

Etapa 5 · 12

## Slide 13

12. Cierre de la Etapa 5

La plataforma no solo funciona: ahora también tenemos un caso completo de diagnóstico

Síntoma

tironeo + LED errático

✓

Descartes

LED, alimentación, motor aislado

✓

Evidencia

retroceso 1,63° con Kd=0,05

✓

Solución segura

Kp=0,7 · Ki=0 · Kd=0

✓

Próximo paso

FSM producto + app

✓

Este caso muestra el valor de I+D: no quedarse con que “llega”, sino entender por qué se mueve así. También valida la decisión previa: arquitectura escalable, configuración por parámetros y modos de ejecución.

Materias: Proyecto Final · Sistemas de Control · Programación Avanzada · Arquitectura de firmware

esp32-motorized-door-controller

Etapa 5 · 13

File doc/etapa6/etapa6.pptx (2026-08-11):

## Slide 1

Etapa 6

Aplicación desktop
y operación del prototipo

De la lógica embebida validada a una herramienta de operación, configuración y diagnóstico construida con PySide6 y asistencia de Codex.

Operación

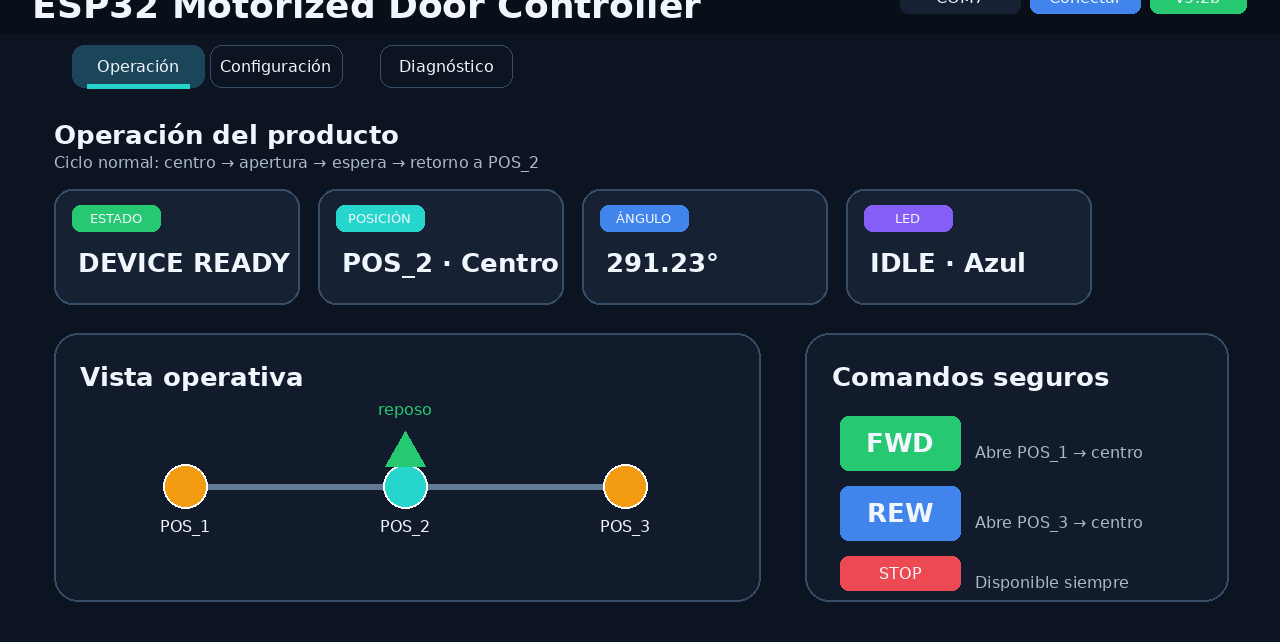
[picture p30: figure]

Configuración


Diagnóstico


La app no reemplaza al firmware: lo observa, lo configura y lo comanda dentro de reglas seguras.

esp32-motorized-door-controller

Etapa 6 · 1

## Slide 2

1. Por qué aparece una aplicación

El firmware ya funciona: ahora hace falta una herramienta para operar y explicar el producto.

Operar FWD/REW sin escribir JSON a mano.
Ver estado, posición, LED y errores en una pantalla común.
Configurar parámetros persistentes sin recompilar.
Separar diagnóstico de operación normal.

NECESIDAD

Una GUI puede mostrar un estado viejo.
Puede habilitar botones cuando el firmware no está listo.
Puede inferir llegada en vez de esperar el evento real.
No debe asumir responsabilidad de seguridad.

RIESGO

El firmware conserva la autoridad sobre movimiento y fallas.
La app consume eventos y respuestas del ESP32.
Codex acelera la construcción, pero el criterio técnico sigue siendo humano.

DECISIÓN I+D

esp32-motorized-door-controller

Etapa 6 · 2

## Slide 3

2. Punto de partida: reutilizar sin arrastrar el dominio anterior

La base PySide6 venía del proyecto de la viga; lo correcto fue conservar infraestructura y reemplazar el caso de uso.

SerialManager: apertura, escritura y lectura serie.
SerialEventQueue: frontera thread-safe entre hilo serie y Qt.
QTimer: consumo periódico de la cola en el hilo principal.
Estructura ui / controllers / core / config.
Widgets reutilizables cuando aportan valor.

SE CONSERVA

Dominio “viga”: distancia, fuerza, reacciones y flexión.
Flujo de ensayo start/distance/force.
Textos, rangos y gauges específicos del banco anterior.
La lógica de negocio del controlador principal.
El protocolo conceptual de producto: puerta, estado y seguridad.

SE REEMPLAZA

Buena práctica: no partir de cero, pero tampoco dejar que un dominio viejo contamine el producto nuevo.

esp32-motorized-door-controller

Etapa 6 · 3

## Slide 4

3. Tres pantallas principales de la aplicación

Cada pantalla responde a un momento distinto del trabajo con el prototipo.

Operación: uso normal del producto


Configuración: parámetros y NVS


Diagnóstico: pruebas y telemetría


Separar pantallas evita mezclar “usuario opera”, “técnico calibra” e “I+D diagnostica”.

esp32-motorized-door-controller

Etapa 6 · 4

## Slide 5

4. Pantalla Operación

Vista pensada para la demo: comandos simples y estado legible.


Comandos FWD y REW para ejecutar el ciclo de apertura y retorno.
STOP siempre visible para cortar el movimiento.
Estado consolidado: READY, movimiento, STOP o DANGER.
Indicadores de posición, LED y versión de firmware.
Oculta detalles técnicos para no cargar la operación normal.

La pantalla de operación debe habilitar botones sólo cuando el firmware confirma que el dispositivo está listo.

FUNCIÓN

esp32-motorized-door-controller

Etapa 6 · 5

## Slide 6

5. Pantalla Configuración

La configuración deja de ser recompilar firmware: se vuelve lectura, edición y escritura controlada.

Posiciones calibradas POS_1, POS_2 y POS_3.
Modo de movimiento y parámetros de control.
LED, brillo, tiempos de demo y espera de apertura.
Acciones: leer, aplicar, restaurar y consultar all-params.
La app traduce formularios en comandos JSON, no en cambios directos de hardware.

La arquitectura JSON/NVS permite recalibrar sin tocar código.

PARÁMETROS


esp32-motorized-door-controller

Etapa 6 · 6

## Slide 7

6. Pantalla Diagnóstico

La pantalla técnica permite probar el sistema sin confundirlo con la operación final.


Ir a POS_1/POS_2/POS_3 para verificar llegada.
Probar FWD/REW y STOP bajo supervisión.
Ver ángulo, error, PWM y eventos recibidos.
Inspeccionar respuestas JSON y all-params.
Distinguir falla física, protocolo, UI o firmware.

Diagnóstico no es “modo usuario”: es una herramienta para I+D, puesta a punto y soporte.

DIAGNÓSTICO

esp32-motorized-door-controller

Etapa 6 · 7

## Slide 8

7. Contrato de comunicación

La app no adivina: pregunta, recibe JSON, actualiza estado y decide qué botones habilitar.

Usuario

click / selección

MainWindow

vista

DoorController

reglas UI

SerialManager

transporte

ESP32

autoridad real

info/version · all-params · fwd · rew · stop · go posX · set params

result · reason · device_state · motion_state · error · parámetros actuales

COMANDOS

EVENTOS

Regla de diseño: si el firmware no confirma, la app no debe inventar que llegó.

esp32-motorized-door-controller

Etapa 6 · 8

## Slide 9

8. Codex como acelerador del desarrollo

La IA escribe rápido; el equipo decide qué arquitectura, qué pruebas y qué comportamiento son aceptables.

Prompt

contexto y límite

1

Código

propuesta Codex

2

Revisión

criterio I+D

3

Prueba

hardware real

4

Ajuste

nuevo prompt

5

Crear estructura de carpetas.
Generar UI PySide6.
Migrar nombres y widgets.
Proponer parsers y controladores.

Validar contra el firmware real.
Definir estados seguros.
Interpretar fallas físicas.
Decidir cuándo commitear o volver atrás.

LO QUE ACELERA

LO QUE NO DELEGA

La IA no conoce el motor, la reductora ni la puerta: el criterio técnico sigue siendo humano.

esp32-motorized-door-controller

Etapa 6 · 9

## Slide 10

9. Prueba real: la UI también se valida

Cuando se pasó a modo real aparecieron diferencias entre mover y saber que se llegó.

Diagnóstico movía el motor hacia la posición.
La app no detectaba correctamente la llegada.
Operación no habilitaba los botones como se esperaba.

El movimiento físico podía estar bien.
El problema estaba en cómo la UI seguía eventos y estados.
Había que respetar la semántica real del firmware.

No inferir llegada desde la acción del botón.
Consumir result/reason/device_state.
Habilitar operación sólo con DEVICE READY confirmado.

SÍNTOMA

LECTURA

CORRECCIÓN

Mover no alcanza: la app debe saber, con evidencia del firmware, qué ocurrió.

esp32-motorized-door-controller

Etapa 6 · 10

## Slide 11

10. Estados separados: conexión, producto y seguridad

Una app confiable no mezcla “puerto abierto” con “puerta lista”.

Puerto abierto/cerrado.
Handshake válido.
Versión y protocolo.
Timeout de respuesta.

BOOT / CENTERING / READY.
OPENING / WAIT / CLOSING.
STOPPED / DIAGNOSTIC.
Resultado de DoorMotion.

DANGER / STOP.
Timeout / stall.
Sensor o estado incoherente.
La decisión crítica vive en ESP32.

COMUNICACIÓN

PRODUCTO

SEGURIDAD

La GUI puede caerse, Windows puede bloquearse o el cable USB desconectarse: el firmware debe seguir siendo seguro.

esp32-motorized-door-controller

Etapa 6 · 11

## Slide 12

11. Cierre de etapa

La app convierte el prototipo técnico en una herramienta demostrable.

Operar

FWD / REW / STOP

1

Configurar

JSON / NVS

2

Diagnosticar

telemetría

3

Validar

eventos reales

4

Presentar

demo integrada

5

La aplicación permite mostrar el producto, no sólo el firmware.
La comunicación y los estados se vuelven visibles para el operador.
La arquitectura de software vuelve a demostrar su valor.

Ensayo integral de demo.
Ajustes de UX para el video.
Documentar comandos mínimos y fallas esperadas.
Cerrar versión presentable del prototipo.

RESULTADO

SIGUIENTE

Etapa 6 cierra el puente entre I+D y demostración: el prototipo ya puede ser operado, explicado y defendido.

esp32-motorized-door-controller

Etapa 6 · 12

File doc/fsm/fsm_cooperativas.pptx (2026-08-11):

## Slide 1

FSM cooperativas

Dispositivo · movimiento · LED conviviendo en un superloop

No hay tres programas corriendo mágicamente: hay un superloop cooperativo. Cada módulo conserva su estado, ejecuta una parte pequeña y devuelve rápido el control.

FSM superior del dispositivo

Decide el estado del producto

FSM de posicionamiento

Mide, calcula y mueve

FSM visual LED

Muestra estado y sentido

Clave de la etapa

esp32-motorized-door-controller

FSM · 1

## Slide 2

1. El problema a resolver

Motor, sensor, LED, switch y host deben convivir sin volver al monolito

FSM

El motor puede estar abriendo o retornando al centro.

El sensor AS5048A debe leerse de forma periódica.

La tira LED debe animar sin frenar el control.

El switch DANGER y el STOP deben seguir disponibles.

La app puede pedir estado o enviar comandos.

Decisión de arquitectura

Separar responsabilidades en máquinas cooperativas y coordinar todo desde el .ino.

La FSM superior decide el comportamiento del producto.

DoorMotion resuelve llegada, cruce, stall y timeout.

CLedStrip traduce estados a feedback visual.

Cada update retorna rápido: no bloquea al resto.

Situación real

I+D: diagnosticar requiere aislar responsabilidades

esp32-motorized-door-controller

FSM · 2

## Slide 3

2. Tres FSM, tres niveles de decisión

El sistema separa producto, movimiento físico y representación visual

PID = algoritmo dentro de MOVING. DANGER = evento de entrada interpretado por la FSM superior.

FSM

Producto

FSM superior

BOOT / CENTERING

READY

OPENING_FWD / REW

OPEN_WAIT

CLOSING_CENTER

STOPPED / DANGER

PID y switch DANGER no son FSM separadas

esp32-motorized-door-controller

Posicionamiento

CDoorMotion

IDLE

START

MOVING

SETTLING

HOLDING reservado

control dentro de MOVING

Visual

CLedStrip

IDLE / READY

MOVING_FWD

MOVING_RWD

ARRIVED / SETTLE

STOP / DANGER

animación por timer

FSM · 3

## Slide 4

3. El .ino como coordinador

Una vuelta del loop() atiende comunicación, eventos y tres update() independientes

FSM

loop() simplificado

1. readSerialCommands();

Cada bloque lee su contexto y decide sólo lo que le corresponde.

No hay delay largos ni espera activa hasta que “termine” una tarea.

El estado queda guardado dentro de cada módulo.

La siguiente vuelta continúa desde donde quedó.

Regla práctica

2. readDangerButtonWithDebounce();

3. updateDeviceFsm();

4. DoorMotion.update();

5. updateLedStripStateFromRuntime();

6. LedStrip.update();

esp32-motorized-door-controller

FSM · 4

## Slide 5

4. FSM superior del dispositivo

Representa el producto: qué ciclo se está ejecutando y qué eventos tienen sentido

La FSM de producto no calcula PWM ni anima LEDs: decide si corresponde abrir, cerrar, esperar, parar o entrar en DANGER.

Por eso un mismo evento no siempre vale: DANGER se acepta en READY, pero puede ignorarse durante un movimiento si no corresponde.

FSM

OPENING
FWD / REW

OPEN_WAIT
timer

BOOT

CENTERING
Ir a POS_2

READY
reposo POS_2

CLOSING
CENTER

DANGER
sólo READY

STOPPED

Lectura didáctica

esp32-motorized-door-controller

FSM · 5

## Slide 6

5. FSM de posicionamiento: CDoorMotion

Resuelve el movimiento físico sin conocer la lógica completa del producto

FSM

IDLE

START
define target

MOVING
sensor + control

SETTLING
frenado breve

IDLE
summary

Durante MOVING

Lee AS5048A y calcula error angular.

Aplica PWM fijo, approach o P/PID según motion_mode.

Vigila llegada, cruce, stall y timeout.

Separación clave

El PID no decide “abrir una puerta”. Sólo calcula esfuerzo de control mientras DoorMotion está en MOVING.

El resultado vuelve a la FSM superior como llegada, cancelación, timeout o error.

esp32-motorized-door-controller

FSM · 6

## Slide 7

6. FSM visual: CLedStrip

La tira WS2812B no manda sobre el motor: representa estado, dirección y alarma

FSM

MOVING_FWD
patrón adelante

IDLE / READY
azul

ARRIVED / SETTLE
transición

STOP / DANGER
rojo / alerta

MOVING_RWD
patrón retorno

Punto de diagnóstico

Al principio el salto del LED parecía otro problema. Después vimos que seguía el sentido que DoorMotor informaba.

El LED no causaba el tironeo: lo hacía visible. Era evidencia de la inversión breve de sentido comandada al puente H.

Conclusión

esp32-motorized-door-controller

FSM · 7

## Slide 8

7. Vista completa: FSM cooperativas en paralelo

Mapa general de relaciones entre producto, posicionamiento y LED

Este gráfico es el mapa conceptual para explicar la convivencia: la FSM superior ordena, DoorMotion ejecuta el posicionamiento y CLedStrip traduce estados/sentidos a visualización.

FSM


esp32-motorized-door-controller

FSM · 8

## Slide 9

8. Ejemplo de convivencia: ciclo FWD

En una apertura el usuario ve simultaneidad, pero el firmware trabaja cooperativamente

FSM


esp32-motorized-door-controller

Mientras la puerta abre

La FSM superior está en DEV_OPENING_FWD y espera el resultado de DoorMotion. STOP conserva prioridad de comando.

DoorMotion está en MOVING

Lee sensor, calcula control, acciona motor y detecta llegada, cruce, stall o timeout cada ~5 ms.

CLedStrip está en MOVING_FWD

La animación corre por su propio timer. No mueve motor ni bloquea control.

FSM · 9

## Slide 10

9. Qué errores evita esta arquitectura

El valor no es sólo “ordenar código”: es poder diagnosticar sin romper lo que funciona

Todo mezclado: app, LEDs, motor, sensor, timers y seguridad.

Una espera larga impide atender STOP, DANGER o el host.

El LED parecía fallar; en realidad mostraba el sentido real del motor.

Sin modos de ejecución se pierde el baseline y no se sabe qué cambió.

FSM

Volver al monolito

Bloquear el loop()

Confundir causa con síntoma

Tocar todo a la vez

esp32-motorized-door-controller

FSM · 10

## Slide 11

10. Cierre: tres FSM, una sola intención de producto

El .ino coordina; cada módulo conserva su estado y su responsabilidad

La modularización permitió probar, aislar, simular y corregir sin perder el control del sistema completo.

La concurrencia en firmware embebido muchas veces no empieza con hilos: empieza con estados pequeños, updates rápidos y responsabilidades claras.

FSM

Arquitectura como herramienta de I+D

Producto

Decide qué debe pasar: READY, abrir, esperar, cerrar, detener o alertar.

Movimiento

Lee posición, calcula control y devuelve resultado físico.

LED

Comunica al usuario lo que el sistema realmente está haciendo.

Conclusión didáctica

esp32-motorized-door-controller

FSM · 11

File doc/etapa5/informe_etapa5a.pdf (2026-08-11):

esp32-motorized-door-controller | Evidencia técnica para informe final


Caso de estudio I+D - Diagnóstico de tironeo tras reemplazo del motor N20 | Página 1

## CASO DE ESTUDIO I+D 01

# Diagnóstico experimental de tironeo tras el reemplazo del motor N20

## Proyecto esp32-motorized-door-controller

Borrador consolidado para el informe final / trabajo práctico integrador Fecha de consolidación: 26 de julio de 2026 Firmware de diagnóstico: v5.1d-led-sim-sensor-runtime

Figura 1. Arquitectura de hardware del prototipo utilizada durante el diagnóstico.

Caso de estudio I+D - Diagnóstico de tironeo tras reemplazo del motor N20 | Página 2

## Resumen ejecutivo

Evento disparador. Tras reemplazar el motor N20 de 6 V, el prototipo continuó llegando correctamente a las posiciones, pero apareció un tironeo físico perceptible. El efecto visual de la tira LED parecía coincidir con esas sacudidas, por lo que inicialmente no era posible separar software, alimentación, sensor, driver y mecánica.

Método. Se aplicó una secuencia de pruebas controladas, manteniendo el mismo firmware y modificando una sola variable por vez: simulación de posición sin alimentar el motor, LED deshabilitado, capacitor bulk en VM, modo de PWM fijo, registro por Serial Plotter y eliminación temporal del término derivativo.

Hallazgo. El tironeo desapareció tanto con PWM fijo como con Kd=0. La gráfica con Kd=0,05 mostró un retroceso real acumulado de 1,63° cerca del objetivo. El período de muestreo permaneció estable entre 5000 y 5006 µs. La evidencia apunta a la interacción entre el término derivativo, la selección de sentido y el PWM mínimo efectivo, y no a un bloqueo temporal, a la FSM LED o a una falta simple de capacidad en VM.

Decisión de proyecto. Se conserva el set seguro con Kd=0 y se difiere la corrección estructural del PD. El caso queda documentado como evidencia central del proceso de I+D y se continúa con el desarrollo de software: modo LED rojo y posterior finalización de la aplicación desktop con Codex.

Variable | Estado consolidado
LED/FSM visual | Descartada como causa primaria mediante led-sim con motor sin alimentación.
Carga de la tira LED | Descartada: el motor tironeó también con led_enabled=0.
Capacidad local en VM | 220 µF agregado; no eliminó el síntoma.
Hardware motor/driver | Capaz de movimiento suave con PWM fijo.
Período de control | Estable: 5000-5006 µs en las pruebas relevantes.
Término D | Implicado: Kd=0,05 produce reversión; Kd=0 elimina el tironeo.
Set operativo actual | Kp=0,7; Ki=0; Kd=0; PWM max=80; PWM mínimo efectivo=70.

## 1. Contexto técnico

- ESP32-S3 Dev Module.
- Motor N20 de 6 V, reemplazado luego de una falla mecánica del motor anterior.
- Puente H DRV8833: STBY GPIO4, AIN2 GPIO16 y AIN1 GPIO17.
- Sensor angular AS5048A por SPI: CS10, MOSI11, SCK12 y MISO13.
- Tira WS2812B de 8 LED en GPIO6.
- Posiciones calibradas: POS_1=2,29°, POS_2=291,23°, POS_3=206,06°.
- Control periódico nominal: 5000 µs.
- Firmware validado previo al diagnóstico: v5.1c-led-arrival-soft-transition.

Caso de estudio I+D - Diagnóstico de tironeo tras reemplazo del motor N20 | Página 3

## 2. Síntoma y pregunta de investigación

El motor nuevo cumplía la función de posicionamiento y los resúmenes terminaban con reason=posicion_alcanzada y stall_count=0/3. Sin embargo, visualmente se observaban pequeñas patadas o cambios bruscos de movimiento, especialmente cerca de la llegada. Como el LED parecía acompañar el tirón, se formuló la pregunta:
¿El tironeo nace en la lógica visual, en la alimentación, en la interacción motor-LED, en el sensor/driver o en el control de movimiento?

## 3. Hipótesis iniciales

1. La FSM LED o pixels.show() introduce pausas o cambios temporales.
2. La tira LED provoca caída de tensión o ground bounce.
3. El nuevo motor consume más y la alimentación local del DRV8833 es insuficiente.
4. El sensor AS5048A o el DRV8833 introducen ruido durante el movimiento real.
5. El controlador PD genera variaciones de PWM o cambios de sentido que no aparecen en el resumen final.

## 4. Estrategia experimental de I+D

La estrategia fue deliberadamente incremental. Cada ensayo buscó falsar una hipótesis con el menor cambio posible, conservando el mismo hardware y, cuando era posible, el mismo binario.

Etapa | Cambio controlado | Qué se aisló
1 | led-sim runtime con VM del motor desconectada | FSM LED, temporización visual y alimentación lógica sin corriente del motor.
2 | led_enabled=0 con movimiento real | Influencia eléctrica y temporal de la tira LED.
3 | 220 µF entre VM y GND del módulo | Falta simple de reserva local en la alimentación del motor.
4 | motion_mode=0, PWM fijo | Control PD fuera del lazo; permanecen motor, driver, sensor y mecánica.
5 | Serial Plotter | Evolución temporal del desplazamiento y detección del retroceso.
6 | motion_mode=2 con Kd=0 | Aislamiento específico del término derivativo.

## 5. Secuencia de ensayos y resultados
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

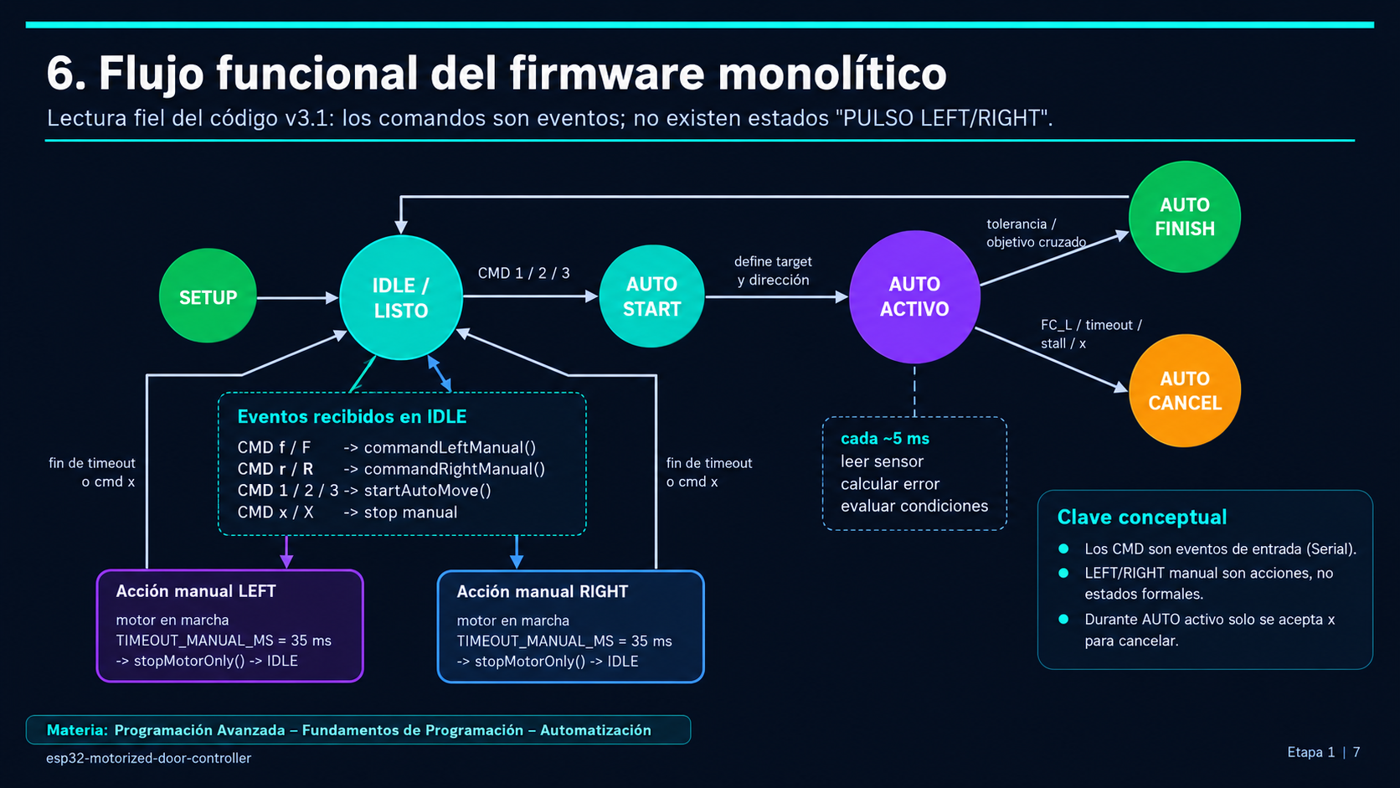
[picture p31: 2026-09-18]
doc/etapa1/etapa1_revision_fsm.png

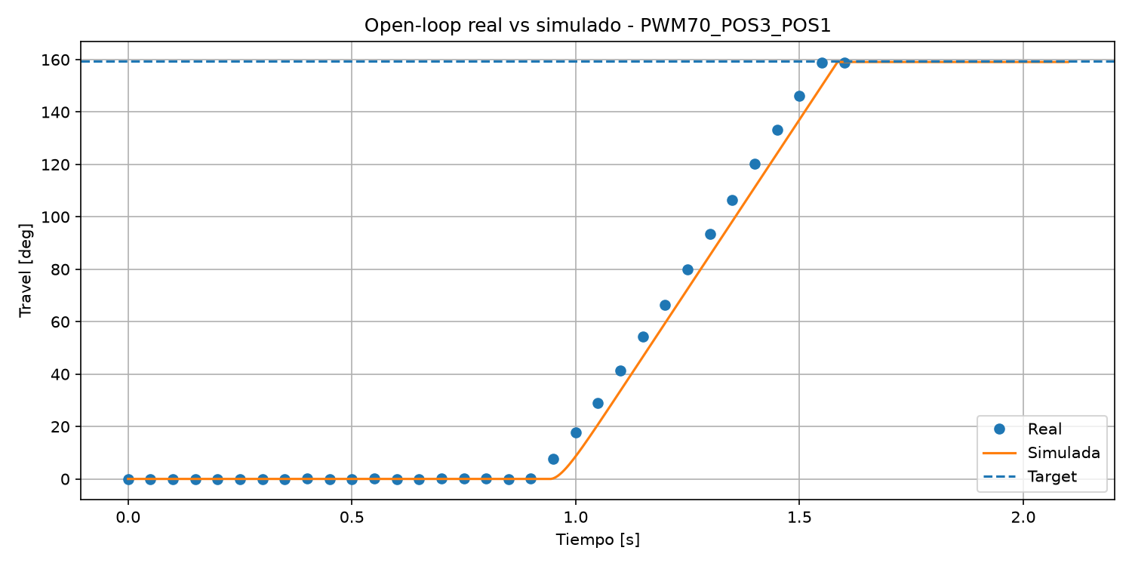
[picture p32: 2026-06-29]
simulacion/simulation_output/03_open_loop_PWM70_POS3_POS1.png

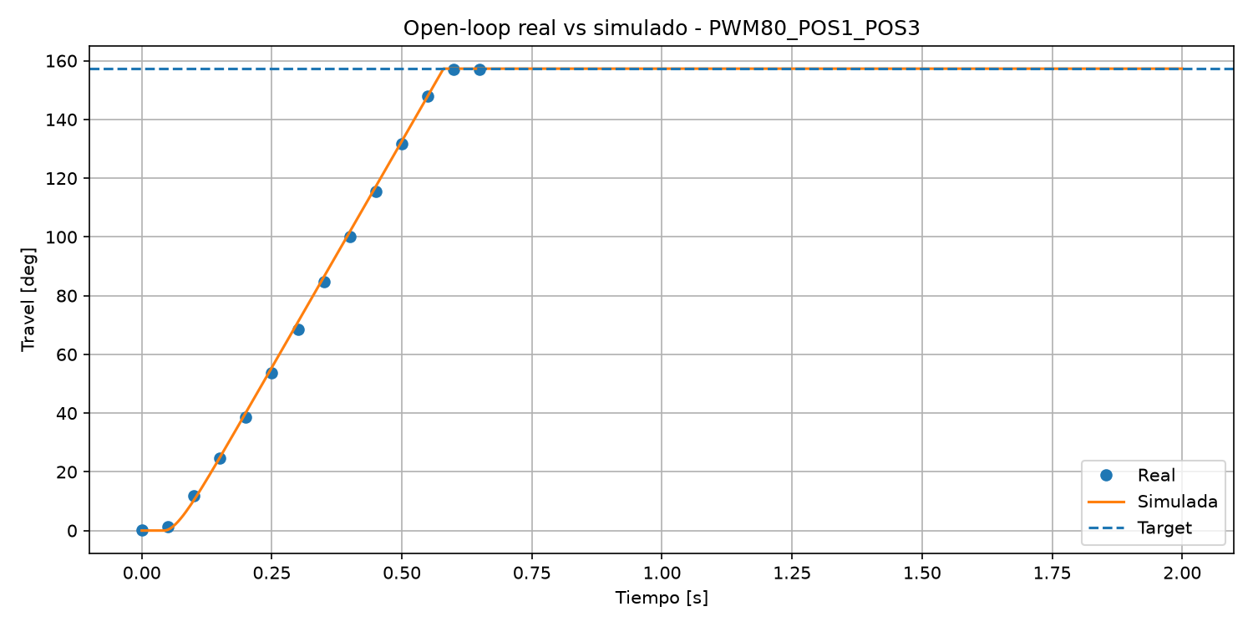
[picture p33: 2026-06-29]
simulacion/simulation_output/03_open_loop_PWM80_POS1_POS3.png

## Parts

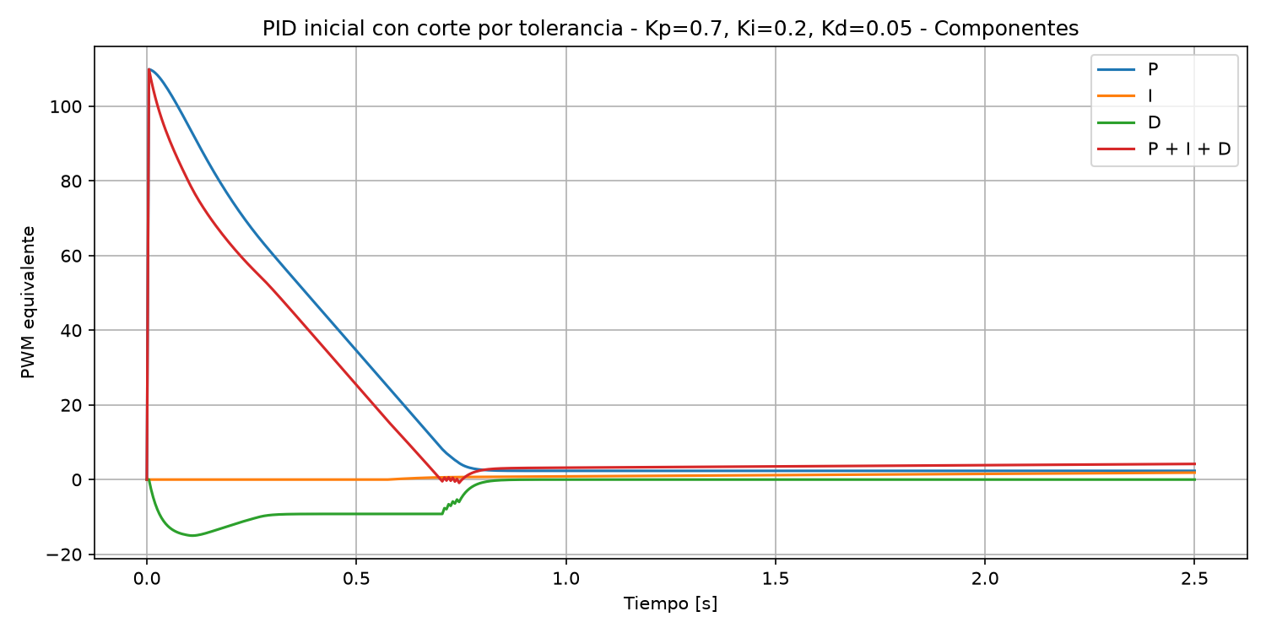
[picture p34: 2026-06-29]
simulacion/simulation_output/07_pid_inicial_con_corte_componentes.png

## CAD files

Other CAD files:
cad/Base v28.f3d
cad/soporte_base v52.f3d

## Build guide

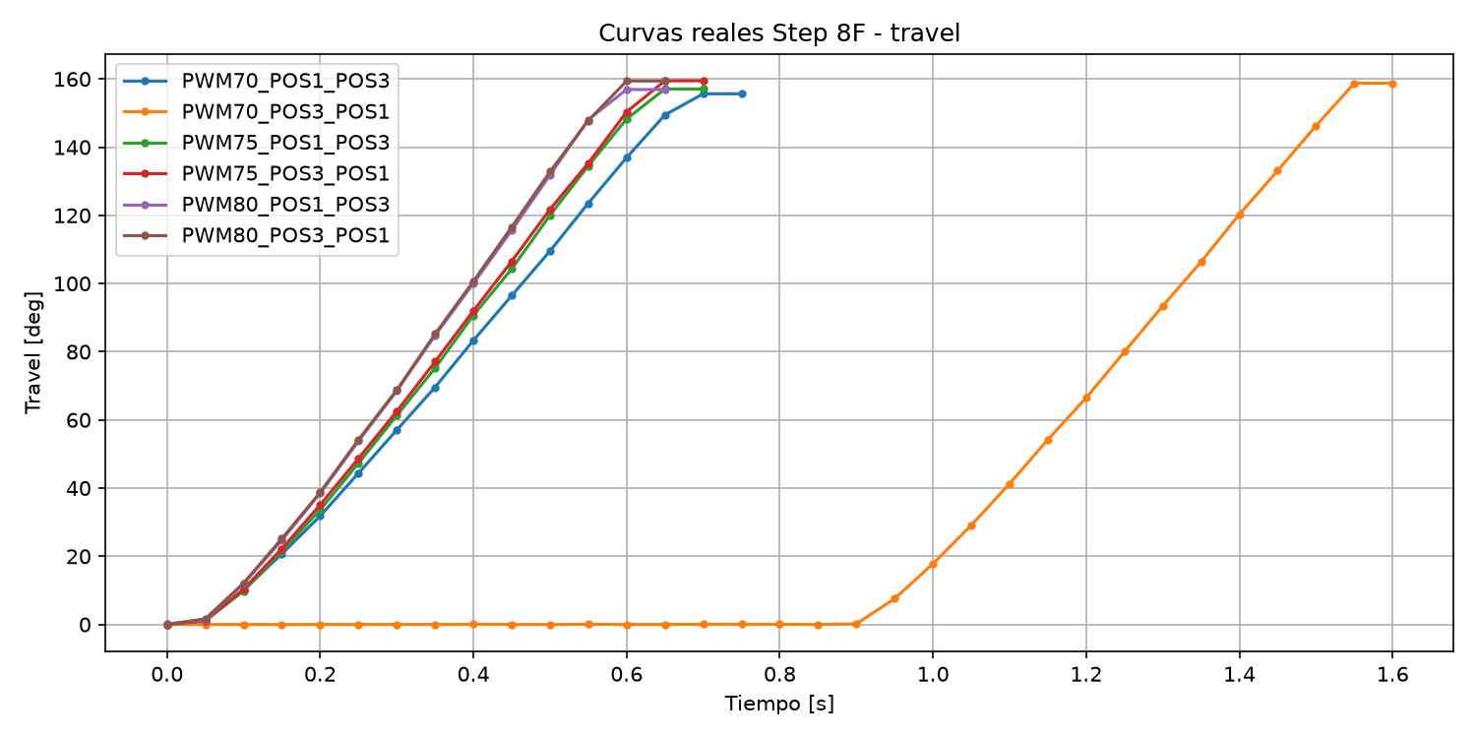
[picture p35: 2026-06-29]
simulacion/simulation_output/01_curvas_reales_step8F.png

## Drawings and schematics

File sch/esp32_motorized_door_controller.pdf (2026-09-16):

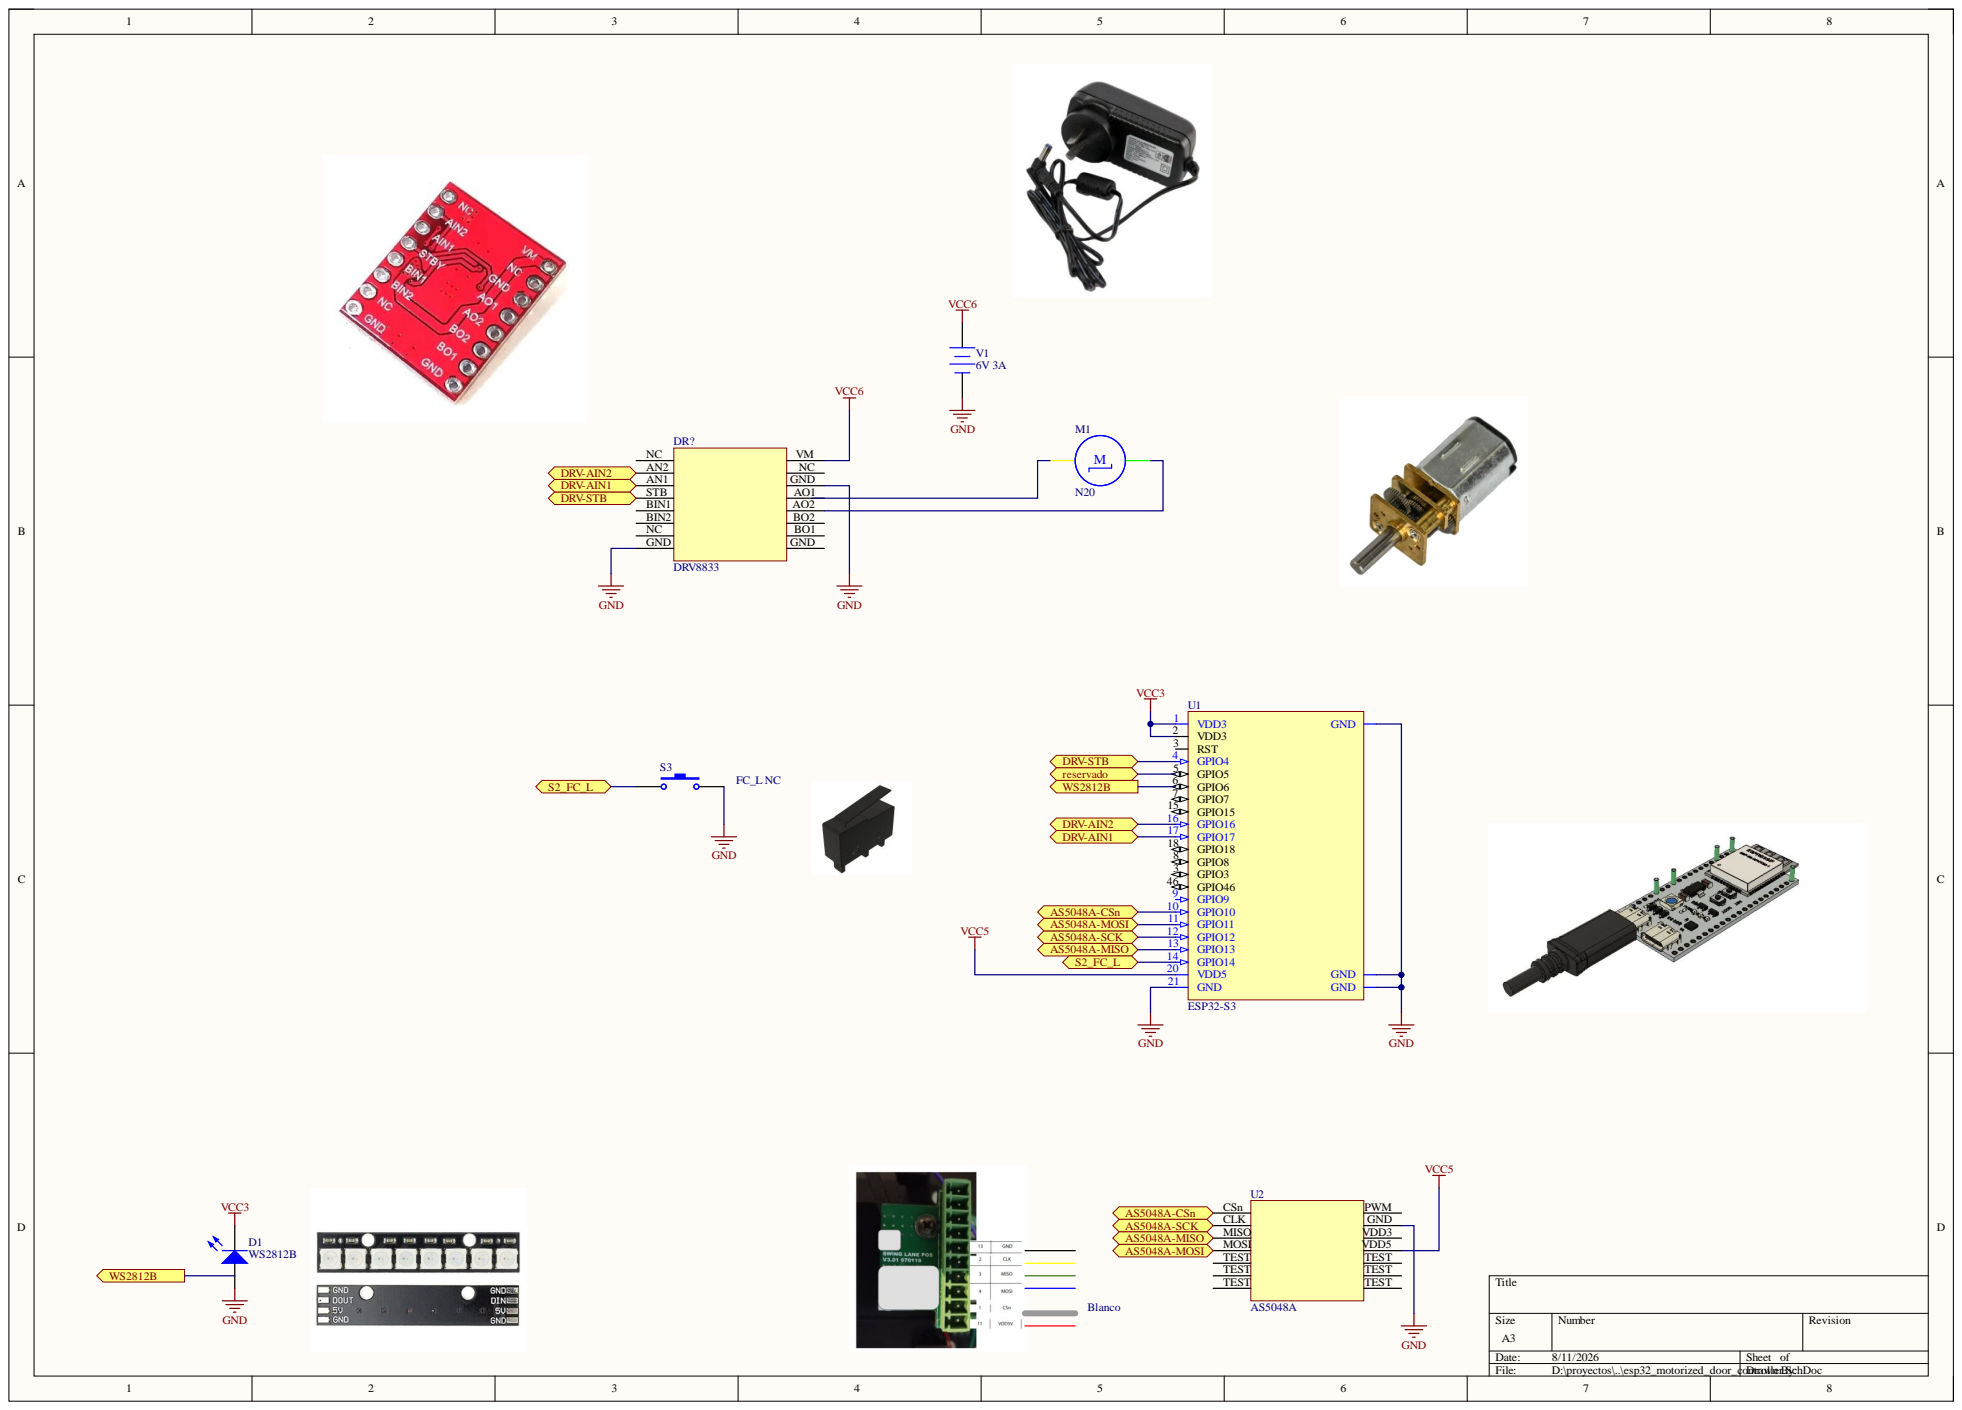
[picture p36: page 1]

NC
GND
AO1
AO2
BO2

S2_FC_L | GPIO14 14 VDD5 20

GND 21

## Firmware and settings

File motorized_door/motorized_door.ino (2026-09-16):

// C:\Users\ptavolaro\AppData\Local\arduino\sketches

#include <Arduino.h>
#include <SPI.h>
#include <math.h>

#include <SimpleFOC.h>
#include <SimpleFOCDrivers.h>
#include "encoders/as5048a/MagneticSensorAS5048A.h"

#include "door_config.h"
#include "door_motion.h"
#include "door_motor.h"
#include "door_angle_sensor.h"
#include "door_led_strip.h"
#include "timer.h"
#include "button.h"
#include "log.h"

/*
  ============================================================
  PROYECTO: ESP32 MOTORIZED DOOR CONTROLLER
  VERSION: v5.2d-mechanical-path
  ============================================================

  ALCANCE ACTUAL
  ------------------------------------------------------------
  - ESP32-S3 + DRV8833 + motor N20 6 V.
  - AS5048A por SPI como realimentacion angular.
  - Posicionamiento modular mediante CDoorMotion.
  - Control configurable por motion_mode.
  - Default validado para el motor nuevo: motion_mode=2,
    Kp=0.7, Ki=0, Kd=0, PWM maximo 80 y minimo efectivo 70.
  - FSM superior de demo:
      centra automaticamente en POS_2 al arrancar en st_mode=0;
      fwd abre a POS_1, espera y vuelve a POS_2;
      rew abre a POS_3, espera y vuelve a POS_2.
  - FSM LED WS2812B:
      IDLE azul; apertura verde; espera verde fija;
      cierre rojo desplazandose; ARRIVED suave.
  - Pulsador DANGER en GPIO14:
      se atiende solamente en DEV_READY, con puerta centrada en POS_2;
      activa rojo intermitente durante danger_time_ms y vuelve a READY.
  - led-sim runtime para diagnostico:
      usa el mismo camino DoorMotion/DoorMotor/FSM LED;
      reemplaza solamente la lectura angular por una posicion virtual.
      Para ensayar sin movimiento fisico se desconecta VM/6 V.

  ARQUITECTURA
  ------------------------------------------------------------
  motorized_door.ino
    Coordina host JSON, estado superior, movimiento, sensor y LED.

  CDoorConfig
    Configuracion RAM/NVS y protocolo JSON.

  CDoorMotion
    FSM de posicionamiento: START, MOVING, SETTLING e IDLE.

  CDoorMotor
    Salida DRV8833: STBY, AIN1, AIN2 y PWM.

  CDoorAngleSensor
    Lectura del AS5048A y medicion de tiempo de acceso.

  CLedStrip
    FSM visual no bloqueante de la tira WS2812B.

  NOTAS
  ------------------------------------------------------------
  - HOLDING activo permanece reservado para hardware real de bloqueo.
  - st_mode=100 evita el centrado automatico y reserva el equipo para pruebas.
  - open_wait_ms y danger_time_ms se cargan desde NVS a la copia RAM de CDoorConfig.
  - El problema de tironeo observado tras cambiar el motor fue aislado
    al termino D de la implementacion actual. Con Kd=0 el movimiento y
    la animacion LED quedaron validados.
  - La referencia completa de comandos y defaults vive en readme.md.
  ============================================================
*/
// ============================================================
// VERSION
// ============================================================

#define APP_VERSION "v5.2d-mechanical-path"

// ============================================================
// PINES
// ============================================================

// DRV8833
#define STBY_PIN 4
#define AIN2_PIN 16
#define AIN1_PIN 17

// Pulsador DANGER (hardware existente en GPIO14)
#define DANGER_BUTTON_PIN 14
#define DANGER_BUTTON_ACTIVE_LEVEL HIGH

// AS5048A SPI
#define AS5048_CS   10
#define AS5048_MOSI 11
#define AS5048_SCK  12
#define AS5048_MISO 13

// Tira RGB WS2812B
#define RGB_LED_DATA 6

// ============================================================
// CONFIGURACION GENERAL
// ============================================================

#define SERIAL_BAUD 115200

#define PWM_FREQ 1000
#define PWM_RES  8

#define PWM_TEST 70
#define PWM_STEP 5
#define PWM_MIN  0
#define PWM_MAX  255

#define TIMEOUT_MANUAL_MS 35

#define POS_MEDIO_APROX_DEG 315.0f

// Posiciones calibradas reales.
#define POS_1_DEFAULT_DEG 2.29f
#define POS_2_DEFAULT_DEG 291.23f
#define POS_3_DEFAULT_DEG 206.06f

// Stream manual de posicion.
// Por defecto apagado para no cargar Serial.
#define STREAM_PERIOD_MS 100UL

// Plotter de planta/control.
// En motion_mode=0:
//   travel vs tiempo de muestra permite ver la respuesta de planta.
//   tiempo aproximado = cantidad de muestras * PLANT_PLOT_PERIOD_MS.
// Periodo desacoplado del periodo de control para no cargar Serial.
#define PLANT_PLOT_PERIOD_MS 50UL

// ============================================================
// SENSOR / CONFIG / MOTION
// ============================================================

MagneticSensorAS5048A sensor(AS5048_CS);

CDoorConfig Config;
CDoorMotion DoorMotion;
CDoorMotor DoorMotor;
CDoorAngleSensor DoorSensor(sensor);
CLedStrip LedStrip;
CButton DangerButton;
Clog Log;

// ============================================================
// ESTADO DEL PRODUCTO
// ============================================================

/*
  DeviceState representa el estado general del producto.
  DoorMotion tiene su propia maquina interna de posicionamiento.
  DoorMotor solo refleja/ejecuta la salida fisica aplicada al DRV8833.
  DoorSensor encapsula la lectura fisica AS5048A.
*/

enum DeviceState {
  DEV_BOOT,
  DEV_CENTERING,
  DEV_READY,
  DEV_OPENING_FWD,
  DEV_OPENING_REW,
  DEV_OPEN_WAIT,
  DEV_CLOSING_CENTER,
  DEV_DIAGNOSTIC_POSITIONING,
  DEV_MANUAL_MOVING,
  DEV_DANGER,
  DEV_STOPPED
};

enum DemoCycleKind : uint8_t {
  DEMO_CYCLE_NONE = 0,
  DEMO_CYCLE_FWD,
  DEMO_CYCLE_REW
};

DeviceState deviceState = DEV_BOOT;
DemoCycleKind activeDemoCycle = DEMO_CYCLE_NONE;

bool streamEnabled = false;

// Manual
CTimer manualMoveTimer;

// Espera no bloqueante con puerta abierta.
// El objeto vive en el .ino; el tiempo viene de la RAM de CDoorConfig.
CTimer openWaitTimer;
uint32_t activeOpenWaitMs = 0;

// Estado DANGER no bloqueante.
// El objeto vive en el .ino; el tiempo viene de la RAM de CDoorConfig.
CTimer dangerTimer;
uint32_t activeDangerTimeMs = 0;

// Movimiento directo de diagnostico.
uint8_t diagnosticTargetPos = 0;

// Stream
CTimer streamTimer;

// Plotter de planta
CTimer plantPlotTimer;
float plantPlotTargetDeg = 0.0f;
float plantPlotStartAbsErrorDeg = 0.0f;
uint16_t plantPlotPwmCmd = 0;

// Cache local para reconfigurar la tira solo cuando cambia algun parametro JSON/NVS.
uint32_t ledCfgEnabled = 0xFFFFFFFFUL;
uint32_t ledCfgCount = 0xFFFFFFFFUL;
uint32_t ledCfgBrightness = 0xFFFFFFFFUL;
uint32_t ledCfgStepMs = 0xFFFFFFFFUL;
uint32_t ledCfgBreathMs = 0xFFFFFFFFUL;
uint32_t ledCfgBlinkMs = 0xFFFFFFFFUL;

// led-sim usa el recorrido normal; solo reemplaza temporalmente al AS5048A.
bool ledSimActive = false;
uint8_t ledSimFromPos = 0;
uint8_t ledSimToPos = 0;
uint32_t ledSimDurationMs = 0;
uint32_t ledSimStartMs = 0;
DeviceState ledSimReturnState = DEV_STOPPED;

bool isPositionActive() {
  return DoorMotion.is_active();
}

// ============================================================
// UTILIDADES ANGULARES
// ============================================================

float normalize360(float deg) {
  return CDoorMotion::normalize360(deg);
}

float angleErrorDeg(float currentDeg, float targetDeg) {
  return CDoorMotion::angle_error_deg(currentDeg, targetDeg);
}

float angleDistanceDeg(float aDeg, float bDeg) {
  return CDoorMotion::angle_distance_deg(aDeg, bDeg);
}

const char* deviceStateName() {
  switch (deviceState) {
    case DEV_BOOT:
      return "BOOT";

    case DEV_CENTERING:
      return "CENTERING";

    case DEV_READY:
      return "READY";

    case DEV_OPENING_FWD:
      return "OPENING_FWD";

    case DEV_OPENING_REW:
      return "OPENING_REW";

    case DEV_OPEN_WAIT:
      return "OPEN_WAIT";

    case DEV_CLOSING_CENTER:
      return "CLOSING_CENTER";

    case DEV_DIAGNOSTIC_POSITIONING:
      return "DIAGNOSTIC_POSITIONING";

    case DEV_MANUAL_MOVING:
      return "MANUAL_MOVING";

    case DEV_DANGER:
      return "DANGER";

    case DEV_STOPPED:
    default:
      return "STOPPED";
  }
}

bool isNormalExecutionMode() {
  return Config.get_st_mode() == DOOR_ST_MODE_NORMAL;
}

bool isDemoCycleActive() {
  return deviceState == DEV_OPENING_FWD ||
         deviceState == DEV_OPENING_REW ||
         deviceState == DEV_OPEN_WAIT ||
         deviceState == DEV_CLOSING_CENTER;
}

// ============================================================
// SENSOR
// ============================================================

float readLedSimDeg() {
  float fromDeg = Config.get_pos_deg(ledSimFromPos);
  float toDeg = Config.get_pos_deg(ledSimToPos);
  float deltaDeg = angleErrorDeg(fromDeg, toDeg);
  uint32_t elapsedMs = millis() - ledSimStartMs;

  if (elapsedMs >= ledSimDurationMs) {
    return toDeg;
  }

  float progress = (float)elapsedMs / (float)ledSimDurationMs;
  return normalize360(fromDeg + deltaDeg * progress);
}

float readSensorDegMeasured(bool countForMotionStats) {
  (void)countForMotionStats;

  if (ledSimActive) {
    return readLedSimDeg();
  }

  return DoorSensor.read_deg();
}

uint32_t getLastSensorReadUs() {
  return ledSimActive ? 0 : DoorSensor.last_read_us();
}

bool isDangerSwitchActive() {
  return DangerButton.is_active();
}

void syncLogLevel() {
  Log.set_level((uint8_t)Config.get_log_level());
}

void printSensor() {
  Log.msg(
    F("raw=%u deg=%.2f mid=%.2f delta_mid=%.2f rad=%.5f vel_rad_s=%.5f motor=%s pwm=%lu auto=%s device=%s position=%s DANGER_SW=%s"),
    DoorSensor.raw(),
    DoorSensor.deg(),
    POS_MEDIO_APROX_DEG,
    angleErrorDeg(DoorSensor.deg(), POS_MEDIO_APROX_DEG),
    DoorSensor.rad(),
    DoorSensor.vel_rad_s(),
    DoorMotor.state_name(),
    (unsigned long)Config.get_pwm_move(),
    isPositionActive() ? "ON" : "OFF",
    deviceStateName(),
    DoorMotion.state_name(),
    isDangerSwitchActive() ? "ACTIVO" : "NORMAL"
  );
}

void plantPlotIfNeeded() {
  if (Config.get_log_level() != LOG_CTRL_ARDUINO_PLOTTER) {
    return;
  }

  if (!plantPlotTimer.expired_ms(PLANT_PLOT_PERIOD_MS)) {
    return;
  }

  plantPlotTimer.start();

  // No se fuerza una lectura extra del AS5048A.
  // DoorMotion.update() ya actualiza DoorSensor.deg() durante el movimiento.
  float currentDeg = DoorSensor.deg();
  float errorDeg = angleErrorDeg(currentDeg, plantPlotTargetDeg);
  float absErrorDeg = fabs(errorDeg);

  float travelDeg = plantPlotStartAbsErrorDeg - absErrorDeg;

  if (travelDeg < 0.0f) {
    travelDeg = 0.0f;
  }

  Log.plant_plot(
    travelDeg,
    plantPlotStartAbsErrorDeg
  );
}
// ============================================================
// MOTOR / DRV8833
// ============================================================

void stopMotorOnly() {
  DoorMotor.stop_only();
}

void stopMotorOutputOnly() {
  DoorMotor.stop_output_only();
}

void motorRightContinuous(uint8_t pwm) {
  DoorMotor.right_continuous(pwm);
}

void motorLeftContinuous(uint8_t pwm) {
  DoorMotor.left_continuous(pwm);
}

void commandRightManual() {
  Log.msg(F("CMD MOTOR RIGHT MANUAL"));
  deviceState = DEV_MANUAL_MOVING;
  motorRightContinuous((uint8_t)Config.get_pwm_move());
  manualMoveTimer.start();
}

void commandLeftManual() {
  Log.msg(F("CMD MOTOR LEFT MANUAL"));
  deviceState = DEV_MANUAL_MOVING;
  motorLeftContinuous((uint8_t)Config.get_pwm_move());
  manualMoveTimer.start();
}

void checkMotorTimeout() {
  if (isPositionActive()) {
    return;
  }

  if (DoorMotor.is_stopped()) {
    return;
  }

  if (manualMoveTimer.expired_ms(TIMEOUT_MANUAL_MS)) {
    Log.msg(F("AUTO STOP por timeout manual"));
    stopMotorOnly();
    deviceState = DEV_STOPPED;

    readSensorDegMeasured(false);
    printSensor();
  }
}

// ============================================================
// FSM SUPERIOR / HOST REQUESTS
// ============================================================

bool startDoorMotionTo(uint8_t pos, const char* targetName) {
  float targetDeg = Config.get_pos_deg(pos);

  if (!DoorMotion.start(targetDeg, targetName)) {
    return false;
  }

  plantPlotTargetDeg = targetDeg;

  // DoorMotion.start() todavia no ejecuta START, por lo que usamos
  // la ultima lectura disponible del wrapper o la posicion virtual.
  plantPlotStartAbsErrorDeg = fabs(angleErrorDeg(
    ledSimActive ? readLedSimDeg() : DoorSensor.deg(),
    plantPlotTargetDeg
  ));

  // Para identificacion de planta usar motion_mode=0.
  plantPlotPwmCmd = (uint16_t)Config.get_pwm_move();
  plantPlotTimer.start_ms_ago(PLANT_PLOT_PERIOD_MS);

  return true;
}

void setDeviceReady(const char* reason) {
  activeDemoCycle = DEMO_CYCLE_NONE;
  diagnosticTargetPos = 0;
  deviceState = DEV_READY;

  Log.msg(F("DEVICE READY: %s"), reason == nullptr ? "sin_reason" : reason);
}

void setDeviceStopped(const char* reason) {
  activeDemoCycle = DEMO_CYCLE_NONE;
  diagnosticTargetPos = 0;
  deviceState = DEV_STOPPED;

  Log.msg(F("DEVICE STOPPED: %s"), reason == nullptr ? "sin_reason" : reason);
}

void enterDanger() {
  activeDangerTimeMs = Config.get_danger_time_ms();
  dangerTimer.start();
  deviceState = DEV_DANGER;

  Log.msg(F("DEVICE DANGER: %lu ms"), (unsigned long)activeDangerTimeMs);
}

void beginOpenWait() {
  // Se toma una copia RAM al entrar al estado. Cambiar open_wait_ms
  // durante la espera afecta al ciclo siguiente, no al actual.
  activeOpenWaitMs = Config.get_open_wait_ms();
  openWaitTimer.start();
  deviceState = DEV_OPEN_WAIT;

  Log.msg(F("DEMO OPEN WAIT: %lu ms"), (unsigned long)activeOpenWaitMs);
}

bool startDemoOpening(DemoCycleKind cycle) {
  uint8_t targetPos = cycle == DEMO_CYCLE_FWD ? 1 : 3;
  const char* targetName = cycle == DEMO_CYCLE_FWD ? "DEMO_FWD_POS_1" : "DEMO_REW_POS_3";

  activeDemoCycle = cycle;
  deviceState = cycle == DEMO_CYCLE_FWD ? DEV_OPENING_FWD : DEV_OPENING_REW;

  if (!startDoorMotionTo(targetPos, targetName)) {
    setDeviceStopped("motion_start_failed");
    return false;
  }

  return true;
}

void startDemoClosingCenter() {
  deviceState = DEV_CLOSING_CENTER;

  if (!startDoorMotionTo(2, "DEMO_CLOSE_POS_2")) {
    setDeviceStopped("close_start_failed");
  }
}

void handleDoorMotionCompletion() {
  if (!DoorMotion.has_completion_event()) {
    return;
  }

  bool success = DoorMotion.completion_succeeded();
  const char* reason = DoorMotion.completion_reason();
  DeviceState completedState = deviceState;
  DemoCycleKind completedCycle = activeDemoCycle;
  uint8_t completedDiagnosticTargetPos = diagnosticTargetPos;
  bool completedLedSim = ledSimActive;
  float finalDeg = completedLedSim ? readLedSimDeg() : DoorSensor.deg();

  DoorMotion.clear_completion_event();

  if (completedLedSim) {
    uint8_t completedLedSimTargetPos = ledSimToPos;
    float targetDeg = Config.get_pos_deg(completedLedSimTargetPos);

    ledSimActive = false;

    // Un stop durante led-sim deja el equipo detenido, igual que cualquier
    // otra cancelacion explicita del host.
    if (completedState == DEV_STOPPED) {
      return;
    }

    if (success) {
      deviceState = ledSimReturnState;
      Log.msg(F("LED SIM finalizado: reason=%s return=%s"), reason, deviceStateName());
    } else {
      setDeviceStopped(reason);
    }

    Config.send_runtime_completion_event(
      "motion-complete",
      "led-sim",
      completedLedSimTargetPos,
      success,
      reason,
      deviceStateName(),
      finalDeg,
      targetDeg
    );

    return;
  }

  switch (completedState) {
    case DEV_CENTERING:
      if (success) {
        setDeviceReady(reason);
      } else {
        setDeviceStopped(reason);
      }

      Config.send_runtime_completion_event(
        "motion-complete",
        "boot-center",
        2,
        success,
        reason,
        deviceStateName(),
        finalDeg,
        Config.get_pos2_deg()
      );
      break;

    case DEV_OPENING_FWD:
    case DEV_OPENING_REW: {
      const char* cycleCommand = completedState == DEV_OPENING_FWD ? "fwd" : "rew";
      uint8_t targetPos = completedState == DEV_OPENING_FWD ? 1 : 3;

      if (success) {
        beginOpenWait();
      } else {
        setDeviceStopped(reason);

        Config.send_runtime_completion_event(
          "cycle-complete",
          cycleCommand,
          targetPos,
          false,
          reason,
          deviceStateName(),
          finalDeg,
          Config.get_pos_deg(targetPos)
        );
      }
      break;
    }

    case DEV_CLOSING_CENTER: {
      const char* cycleCommand = completedCycle == DEMO_CYCLE_FWD ? "fwd" : "rew";

      if (success) {
        setDeviceReady(reason);
      } else {
        setDeviceStopped(reason);
      }

      Config.send_runtime_completion_event(
        "cycle-complete",
        cycleCommand,
        2,
        success,
        reason,
        deviceStateName(),
        finalDeg,
        Config.get_pos2_deg()
      );
      break;
    }

    case DEV_DIAGNOSTIC_POSITIONING: {
      uint8_t targetPos = completedDiagnosticTargetPos;
      float targetDeg = Config.get_pos_deg(targetPos);

      if (success && targetPos == 2 && isNormalExecutionMode()) {
        setDeviceReady(reason);
      } else {
        setDeviceStopped(reason);
      }

      Config.send_runtime_completion_event(
        "motion-complete",
        "go",
        targetPos,
        success,
        reason,
        deviceStateName(),
        finalDeg,
        targetDeg
      );
      break;
    }

    case DEV_STOPPED:
      // El host cancelo el ciclo mientras DoorMotion terminaba SETTLING.
      // Se consume el evento sin iniciar ninguna accion automatica.
      break;

    default:
      if (!success) {
        setDeviceStopped(reason);
      }
      break;
  }
}

void updateDeviceFsm() {
  handleDoorMotionCompletion();

  if (deviceState == DEV_READY) {
    DangerButton.debounce();

    if (DangerButton.is_pressed()) {
      enterDanger();
      return;
    }
  }

  if (deviceState == DEV_DANGER) {
    if (dangerTimer.expired_ms(activeDangerTimeMs)) {
      setDeviceReady("danger_timeout");
    }

    return;
  }

  if (deviceState == DEV_OPEN_WAIT && openWaitTimer.expired_ms(activeOpenWaitMs)) {
    startDemoClosingCenter();
  }
}

void initializeDeviceFsm() {
  deviceState = DEV_BOOT;
  activeDemoCycle = DEMO_CYCLE_NONE;

  if (!isNormalExecutionMode()) {
    setDeviceStopped("st_mode_test_no_auto_center");
    return;
  }

  float currentDeg = DoorSensor.deg();
  float centerErrorDeg = angleDistanceDeg(currentDeg, Config.get_pos2_deg());

  if (centerErrorDeg <= Config.get_auto_tolerance_deg()) {
    setDeviceReady("boot_already_centered");
    return;
  }

  deviceState = DEV_CENTERING;

  if (!startDoorMotionTo(2, "BOOT_CENTER_POS_2")) {
    setDeviceStopped("boot_center_start_failed");
  }
}

void stopAutomaticActivity() {
  activeDemoCycle = DEMO_CYCLE_NONE;
  deviceState = DEV_STOPPED;

  if (DoorMotion.is_moving_or_starting()) {
    DoorMotion.cancel("cancelado_por_host");
    return;
  }

  if (DoorMotion.is_holding()) {
    DoorMotion.cancel("hold_liberado_por_host");
    return;
  }

  // En SETTLING o OPEN_WAIT el motor ya esta cortado. No se reemplaza
  // el reason original y no se agrega ninguna espera bloqueante.
  if (!DoorMotor.is_stopped()) {
    stopMotorOnly();
  }
}
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
void loop() {
  // Antes de responder info/all-params se toma una lectura fresca cuando
  // el posicionamiento no esta usando el sensor en su propio periodo.
  if (Serial.available() > 0 && !DoorMotion.is_active() && !ledSimActive) {
    readSensorDegMeasured(false);
  }

  Config.set_runtime_status(
    deviceStateName(),
    ledSimActive ? readLedSimDeg() : DoorSensor.deg()
  );

  Config.host_cmd();
  syncLogLevel();
  processHostRequest();

  if (DoorMotion.is_active()) {
    DoorMotion.update();
    plantPlotIfNeeded();
  }

  updateDeviceFsm();
  checkMotorTimeout();
  updateLedStrip();

  if (streamEnabled && streamTimer.expired_ms(STREAM_PERIOD_MS)) {
    streamTimer.start();

    readSensorDegMeasured(false);
    printSensor();
  }
}

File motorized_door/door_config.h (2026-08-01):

#ifndef DOOR_CONFIG_H
#define DOOR_CONFIG_H

#include <Arduino.h>
#include <ArduinoJson.h>
#include <Preferences.h>

/*
  ============================================================
  CDoorConfig
  ------------------------------------------------------------
  Responsabilidad:
    - Configuracion persistente en NVS mediante Preferences.
    - Copia RAM de parametros.
    - Comunicacion host por Serial + ArduinoJson.
    - Pedidos pendientes para que el main decida.

  Regla de arquitectura:
    - Entrada host: SOLO JSON por Serial.
    - Salida host de la clase: SOLO JSON por Serial.
    - NO procesa caracteres sueltos.
    - NO mueve motor.
    - NO lee sensor.
    - NO ejecuta la maquina de estados.
    - NO hace Serial.begin().
  ============================================================
*/

// ============================================================
// NVS
// ============================================================

#define DOOR_CFG_NAMESPACE        "doorcfg"
#define DOOR_CFG_MAGIC_NUMBER     974UL
#define DOOR_CFG_SCHEMA_VERSION   1UL

// ============================================================
// DEFAULTS VALIDADOS - v5.2c / MOTOR N20 NUEVO + RUNTIME EVENTS
// ============================================================

#define DOOR_POS_1_DEFAULT_DEG    2.29f
#define DOOR_POS_2_DEFAULT_DEG    291.23f
#define DOOR_POS_3_DEFAULT_DEG    206.06f

#define DOOR_PWM_MOVE_DEFAULT     80UL

#define DOOR_CONTROL_PERIOD_US_DEFAULT        5000UL
#define DOOR_AUTO_TOLERANCE_DEG_DEFAULT       2.00f
#define DOOR_AUTO_CROSS_MARGIN_DEG_DEFAULT    0.20f
#define DOOR_AUTO_MAX_RUN_MS_DEFAULT          10000UL
#define DOOR_AUTO_STALL_CHECK_MS_DEFAULT      250UL
#define DOOR_AUTO_MIN_MOVE_DEG_DEFAULT        0.30f
#define DOOR_AUTO_STALL_MAX_COUNT_DEFAULT     3UL
#define DOOR_AUTO_FINAL_SETTLE_MS_DEFAULT     80UL

#define DOOR_LOG_LEVEL_DISABLED             0UL
#define DOOR_LOG_LEVEL_MSG                  1UL
#define DOOR_LOG_LEVEL_JSON                 2UL
#define DOOR_LOG_LEVEL_PLOTTER              3UL

#define DOOR_LOG_LEVEL_DEFAULT              DOOR_LOG_LEVEL_MSG

// Tira RGB WS2812B
#define DOOR_LED_ENABLED_DEFAULT            1UL
#define DOOR_LED_COUNT_DEFAULT              8UL
#define DOOR_LED_COUNT_MAX                  60UL
#define DOOR_LED_BRIGHTNESS_DEFAULT         25UL
#define DOOR_LED_STEP_MS_DEFAULT            60UL
#define DOOR_LED_BREATH_MS_DEFAULT          25UL
#define DOOR_LED_BLINK_MS_DEFAULT           180UL

// Ciclo automatico de demo
#define DOOR_OPEN_WAIT_MS_DEFAULT           2000UL
#define DOOR_OPEN_WAIT_MS_MAX               60000UL

// Estado DANGER por pulsador, valido solamente en DEV_READY/POS_2.
#define DOOR_DANGER_TIME_MS_DEFAULT         3000UL
#define DOOR_DANGER_TIME_MS_MAX             60000UL

// Movimiento:
//   0 = baseline fixed PWM.
//   1 = perfil no-PID de aproximacion.
//   2 = control de posicion P/PI/PD/PID durante MOVING, sin HOLDING activo.
#define DOOR_MOTION_MODE_FIXED_PWM             0UL
#define DOOR_MOTION_MODE_APPROACH              1UL
#define DOOR_MOTION_MODE_PD_POSITION           2UL
#define DOOR_MOTION_MODE_DEFAULT               DOOR_MOTION_MODE_PD_POSITION

#define DOOR_PWM_START_DEFAULT                 80UL
#define DOOR_PWM_SLOW_DEFAULT                  60UL
#define DOOR_SLOW_ZONE_DEG_DEFAULT             20.0f
#define DOOR_START_BOOST_MS_DEFAULT            120UL

// Parametros validados para motion_mode=2 con el motor N20 nuevo.
// El default actual es control P: Ki=0 y Kd=0.
#define DOOR_PID_KP_DEFAULT                    0.70f
#define DOOR_PID_KI_DEFAULT                    0.00f
#define DOOR_PID_KD_DEFAULT                    0.00f
#define DOOR_PID_PWM_MAX_DEFAULT               80UL
#define DOOR_PID_PWM_MIN_EFFECTIVE_DEFAULT     70UL
#define DOOR_PID_MIN_EFFECTIVE_ERROR_DEFAULT   2.0f
#define DOOR_PID_I_ACTIVE_ERROR_DEFAULT        20.0f
#define DOOR_PID_INTEGRAL_LIMIT_DEFAULT        120.0f

// ============================================================
// MODO / PEDIDOS HOST
// ============================================================

#define DOOR_ST_MODE_NORMAL       0UL
#define DOOR_ST_MODE_TEST         100UL

enum DoorHostRequest : uint8_t {
  DOOR_REQ_NONE = 0,
  DOOR_REQ_GO_POS_1,
  DOOR_REQ_GO_POS_2,
  DOOR_REQ_GO_POS_3,
  DOOR_REQ_STOP,
  DOOR_REQ_LED_SIM,
  DOOR_REQ_FWD,
  DOOR_REQ_REW
};
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

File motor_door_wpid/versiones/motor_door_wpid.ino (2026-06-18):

// C:\Users\ptavolaro\AppData\Local\arduino\sketches

#include <Arduino.h>
#include <SPI.h>
#include <math.h>

#include <SimpleFOC.h>
#include <SimpleFOCDrivers.h>
#include "encoders/as5048a/MagneticSensorAS5048A.h"

/*
  ============================================================
  PROYECTO: ESP32 MOTORIZED DOOR CONTROLLER
  VERSION: v3.1-continuous-silent-measured

  OBJETIVO DE ESTA VERSION
  ------------------------------------------------------------
  Version de movimiento continuo hacia 3 posiciones, pero con
  Serial silencioso durante el movimiento automatico para no
  afectar el tiempo de muestreo/control.

  Esta version busca medir:
    - si llega o no llega
    - cuanto se pasa
    - tiempo total de movimiento
    - cantidad de muestras tomadas
    - periodo real de muestreo
    - tiempo maximo de lectura del sensor
    - tiempo maximo de calculo/control

  Concepto a validar:
    Con PWM fijo, la respuesta depende de la mecanica real,
    carga, rozamiento, tension, inercia y sentido de movimiento.
    Esta version sirve para buscar PWM minimo y PWM maximo util.

  Hardware:
    - ESP32-S3 Dev Module
    - DRV8833
    - Motor N20/reductor a 6 V
    - AS5048A por SPI
    - FC_L en GPIO14 con INPUT_PULLUP, NC a GND

  Pines AS5048A:
    CSn  -> GPIO10
    MOSI -> GPIO11
    SCK  -> GPIO12
    MISO -> GPIO13
    VDD5V -> 5V0
    GND -> GND comun

  Pines DRV8833:
    STBY -> GPIO4
    AIN2 -> GPIO16
    AIN1 -> GPIO17
    VM -> 6 V motor
    GND comun con ESP32

  Sentido validado:
    - MOTOR LEFT  / FORWARD logico -> sube angulo
    - MOTOR RIGHT / REWIND logico  -> baja angulo

  IMPORTANTE:
    Durante autoMoveActive no se imprime printSensor().
    Solo imprime:
      - comando recibido
      - inicio de automatico
      - resumen final
      - anomalias
  ============================================================
*/

// ============================================================
// VERSION
// ============================================================

#define APP_VERSION "v3.1-continuous-silent-measured"

// ============================================================
// PINES
// ============================================================

// DRV8833
#define STBY_PIN 4
#define AIN2_PIN 16
#define AIN1_PIN 17

// Final de carrera izquierdo
#define FC_L_PIN 14

// AS5048A SPI
#define AS5048_CS   10
#define AS5048_MOSI 11
#define AS5048_SCK  12
#define AS5048_MISO 13

// ============================================================
// CONFIGURACION GENERAL
// ============================================================

#define SERIAL_BAUD 115200

#define PWM_FREQ 1000
#define PWM_RES  8

#define PWM_TEST 70
#define PWM_STEP 5
#define PWM_MIN  0
#define PWM_MAX  255

#define TIMEOUT_MANUAL_MS 35

#define POS_MEDIO_APROX_DEG 315.0f

// Posiciones calibradas reales.
// Se cargan al iniciar el ESP32.
// Los comandos a/b/c pueden cambiarlas en RAM,
// pero no se guardan en memoria permanente.
#define POS_1_DEFAULT_DEG 2.29f
#define POS_2_DEFAULT_DEG 291.23f
#define POS_3_DEFAULT_DEG 206.06f

// Control automatico continuo
#define AUTO_TOLERANCE_DEG       1.50f
#define AUTO_CROSS_MARGIN_DEG    0.20f
#define AUTO_MAX_RUN_MS          10000UL
#define AUTO_STALL_CHECK_MS      250UL
#define AUTO_MIN_MOVE_DEG        0.30f
#define AUTO_STALL_MAX_COUNT     3

// Periodo de control automatico.
// 5000 us = 5 ms = 200 muestras/seg maximo teorico.
#define CONTROL_PERIOD_US        5000UL

// Espera despues de frenar antes de leer posicion final estable.
#define AUTO_FINAL_SETTLE_MS     80UL

// Debug automatico opcional.
// Por defecto apagado.
#define AUTO_DEBUG_PERIOD_MS     250UL

// Stream manual de posicion.
// Por defecto apagado para no cargar Serial.
#define STREAM_PERIOD_MS         100UL

// ============================================================
// SENSOR
// ============================================================

MagneticSensorAS5048A sensor(AS5048_CS);

// ============================================================
// ESTADOS
// ============================================================

enum MotorState {
  MOTOR_STOPPED,
  MOTOR_RIGHT,
  MOTOR_LEFT
};

enum AutoDirection {
  AUTO_DIR_NONE,
  AUTO_DIR_RIGHT,
  AUTO_DIR_LEFT
};

MotorState motorState = MOTOR_STOPPED;
AutoDirection autoDirection = AUTO_DIR_NONE;

bool driverEnabled = false;
bool streamEnabled = false;
bool debugAuto = false;

int pwmManual = PWM_TEST;

float pos1Deg = POS_1_DEFAULT_DEG;
float pos2Deg = POS_2_DEFAULT_DEG;
float pos3Deg = POS_3_DEFAULT_DEG;

// Ultima lectura del sensor
float lastDeg = 0.0f;
float lastRad = 0.0f;
float lastVelRadS = 0.0f;
uint16_t lastRaw = 0;

// Manual
unsigned long lastManualMoveMs = 0;

// Stream
unsigned long lastStreamMs = 0;

// Automatico
bool autoMoveActive = false;

float autoTargetDeg = POS_MEDIO_APROX_DEG;
const char* autoTargetName = "NINGUNA";

float autoStartDeg = 0.0f;
float autoStartErrorDeg = 0.0f;

float autoDecisionDeg = 0.0f;
float autoDecisionErrorDeg = 0.0f;

unsigned long autoStartMs = 0;
unsigned long autoLastStallCheckMs = 0;
unsigned long autoLastDebugMs = 0;

float autoLastStallDeg = 0.0f;
int autoStallCount = 0;

// Medicion de tiempos
uint32_t autoLastControlUs = 0;
uint32_t autoLastSampleUs = 0;

uint32_t autoSamples = 0;
uint32_t autoMinSampleDtUs = 0xFFFFFFFF;
uint32_t autoMaxSampleDtUs = 0;
uint32_t autoMaxSensorUs = 0;
uint32_t autoMaxControlUs = 0;

// ============================================================
// UTILIDADES ANGULARES
// ============================================================

float normalize360(float deg) {
  while (deg < 0.0f) {
    deg += 360.0f;
  }

  while (deg >= 360.0f) {
    deg -= 360.0f;
  }

  return deg;
}

// error = current - target normalizado a [-180, 180]
// Si error > 0: current esta por arriba del target en el camino corto.
// Si error < 0: current esta por debajo del target en el camino corto.
float angleErrorDeg(float currentDeg, float targetDeg) {
  float error = currentDeg - targetDeg;

  while (error > 180.0f) {
    error -= 360.0f;
  }

  while (error < -180.0f) {
    error += 360.0f;
  }

  return error;
}

float angleDistanceDeg(float aDeg, float bDeg) {
  return fabs(angleErrorDeg(aDeg, bDeg));
}

const char* motorStateName() {
  switch (motorState) {
    case MOTOR_RIGHT:
      return "RIGHT";
    case MOTOR_LEFT:
      return "LEFT";
    default:
      return "STOP";
  }
}

const char* autoDirectionName() {
  switch (autoDirection) {
    case AUTO_DIR_RIGHT:
      return "RIGHT";
    case AUTO_DIR_LEFT:
      return "LEFT";
    default:
      return "NONE";
  }
}

// ============================================================
// SENSOR
// ============================================================
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

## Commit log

2026-06-21 refactor: wrap AS5048A angle sensor reading
2026-06-21 refactor: extract DRV8833 motor output
2026-06-29 simulation: agregar simulacion PID inicial
2026-07-02 v4.0: prepare FSM for future hold mode without PID
2026-07-05 v4.1c: add limited integral to PID motion mode
2026-07-08 v5.0b: migrate firmware timing to timer model
2026-07-08 v5.0a: add timer abstraction for control sampling
2026-07-09 WIP v5.1a led strip fsm
2026-07-25 Validate v5.1c LED arrival soft transition
2026-07-25 Add beam app prototype
2026-07-27 Set validated defaults for new motor
2026-08-01 Add demo cycle FSM and danger button state
2026-08-11 chore: snapshot before mechanical path fix
    [log.cpp, main_controller.py]
2026-09-16 v5.2d: fix mechanical path through POS_2
    [door_motion.cpp, motorized_door.ino]
2026-09-16 docs: update project documentation and design files
    [Base v28.f3d, soporte_base v52.f3d]
